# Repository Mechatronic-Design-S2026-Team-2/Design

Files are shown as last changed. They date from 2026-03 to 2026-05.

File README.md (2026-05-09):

# Hexapod Operation README

## Overview

This document describes basic setup, operation, charging, connection, and troubleshooting procedures for the hexapod robot.

---

## Aligning Motor Cranks

For the robot to maintain the expected alternating tripod gait, each input crank — the first bar extending from each motor — should point straight down.

This crank position corresponds to the highest point in the leg movement. If the cranks are not aligned this way, the control computer may incorrectly estimate leg position and phase. The robot may still operate, but gait smoothness may be reduced.

---

## Emergency Disable Switch

The switch mounted on the top surface of the robot disables motor control and the power relays.

| Switch Position | Function |
|---|---|
| `O` | Normal operation |
| `I` | Reset / disabled state |

To reset the motor control system, move the switch to `I` for a few moments, then return it to `O`.

---

## Charging the Robot Battery

1. Turn on the emergency disable switch by moving it to the `I` position.
2. Disconnect the XT90 connector from the board.
3. The battery may either be removed or charged in place.
4. Connect the charger to the smaller XT60 connector on the battery.
5. After the XT60 connector is attached, plug the charger power cord into a standard AC outlet.
6. Both charger LEDs should turn red.
7. When charging is complete, one charger LED will turn green.
8. Disconnect the charger from AC power first.
9. Disconnect the XT60 connector between the charger and the battery.

---

## Connecting to the Robot

### Wi-Fi

The robot hosts a Wi-Fi network with the following credentials:

| Field | Value |
|---|---|
| SSID | `team2` |
| Password | `MECHATRONICS` |
| Robot IP | `192.168.50.1` |

### Ethernet

When connected through the Jetson Ethernet port, the robot IP is:

```text
192.168.55.2
```

---

## SSH Access

The robot operating system credentials are:

| Field | Value |
|---|---|
| Username | `team2` |
| Password | `MECHATRONICS` |

Example SSH command over Wi-Fi:

```bash
ssh team2@192.168.50.1
```

Example SSH command over Ethernet:

```bash
ssh team2@192.168.55.2
```

---

## Accessing the Robot Control Interface

The robot control interface is available in a web browser.

### Over Wi-Fi

```text
http://192.168.50.1:8080
```

### Over Ethernet

```text
http://192.168.55.2:8080
```

Any modern desktop or laptop web browser should work.

When the control interface tab is active, pressing the displayed keyboard keys will command robot movement. The main map display can be used to view robot movement, the current occupancy grid map, generated maps, and waypoint placement.

Map saving and loading controls are located near the bottom of the right sidebar, along with key bindings, status information, and maximum velocity settings.

---

## Troubleshooting Wi-Fi

Under normal conditions, if the battery is charged, the Wi-Fi network should appear a few seconds after the battery is connected.

If the Wi-Fi network does not appear:

1. Check normal client-device Wi-Fi issues first.
2. Inspect the Jetson Nano located at the back-left corner inside the chassis.
3. Confirm that the green LED on the left side of the Jetson is on.
4. If the Jetson is not powered, check that the power jack connection is secure.

---

## Troubleshooting the Control Interface

If the robot and control device are connected, but the web control interface does not load:

1. Verify that the URL matches the connection method:
   - Wi-Fi: `http://192.168.50.1:8080`
   - Ethernet: `http://192.168.55.2:8080`
2. Open an SSH session to the robot.
3. Run the following commands:

```bash
docker exec -it jazzy bash
sudo systemctl restart orbslam2-realsense.service
sudo systemctl restart hexapod-ros2-full-launch.service
```

---

## Troubleshooting Robot Motion

If the robot does not move its legs when a nonzero motion command is sent, the most likely issue is the emergency disable state.

1. Move the emergency disable switch to `I`.
2. Wait a few moments.
3. Move the switch back to `O`.

The red PCB module on the right side of the robot has three LEDs. The two smaller LEDs should flash initially, then remain on.

If the LEDs do not remain on:

1. Disconnect and reconnect the USB-C cable connected to the ESP32.
2. Check the USB-A side of the cable connected to the Jetson.
3. Repeat the emergency switch reset procedure.

If the robot still does not move, restart the micro-ROS and ROS containers:

```bash
docker restart microros_agent
docker restart jazzy
```

---

## Foot Adjustment

The feet are height-adjustable relative to the leg assemblies. Before operation, verify that the feet make proper contact with the ground.

The legs may be moved manually when the robot is unpowered, or the robot may be walked using the standard control interface.

Adjustment guidance:

| Condition | Adjustment |
|---|---|
| Feet slip while walking | Rotate the threaded bolt holding the rubber foot pad counterclockwise |
| Feet extend too far and support wheels lose ground contact | Rotate the threaded bolt clockwise |

---

## Caster Wheel Adjustment

The caster wheels at each corner of the robot are also mounted using threaded bolts.

If the caster wheels have inconsistent heights, rotate the threaded bolts to adjust their height until the chassis is properly supported.

---

## Battery BMS Access

The battery includes a Bluetooth-enabled Daly BMS. BMS settings related to current output and protection can be accessed while the battery is actively charging or discharging.

| Field | Value |
|---|---|
| Bluetooth ID | `52V 25ah` |
| App | Daly BMS app |
| Password | `123456` |

To access the BMS:

1. Download the Daly BMS app.
2. Ensure the battery is actively charging or discharging.
3. Search for the Bluetooth ID `52V 25ah`.
4. Connect using password `123456`.

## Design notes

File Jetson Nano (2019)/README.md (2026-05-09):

# Hexapod ROS 2 Workspace

This workspace contains the Jetson-side ROS 2 Jazzy stack for the Klann-linkage hexapod. It is intended to live at `/ros2_ws` inside the existing ROS 2 container. The archive intentionally excludes `build/`, `install/`, and `log/` so it can be copied onto the Jetson and rebuilt in place.

The current stack assumes the RealSense D415 and ORB-SLAM2 process run on the bare-metal Jetson, while ROS 2, Nav2, SLAM Toolbox, the browser operator interface, hardware aggregation, and tripod gait controller run inside the `jazzy` container. The ESP32/micro-ROS bridge is expected to be provided separately by the `microros_agent` container.

## Current system architecture

### Bare-metal Jetson

`orbslam2-realsense.service` owns the RealSense D415 and runs the CUDA ORB-SLAM2 RGB-D frontend. It exports pose, map points, and a virtual planar scan to UDP port `5005`.

The Jetson also runs host-side systemd helpers:

- `hexapod-ros2-full-launch.service`: executes the full ROS 2 launch inside the already-running `jazzy` container.
- `hexapod-host-control.service`: exposes limited localhost-only HTTP actions for the browser GUI, such as restarting ORB-SLAM2 or the `microros_agent` container.

### ROS 2 container

The main runtime chain is:

```text
ORB-SLAM2 bare-metal UDP packets
  -> hexapod_orbslam_udp_bridge
  -> /hexapod/orbslam_odom
  -> /orbslam/map_points
  -> /scan_raw

/scan_raw
  -> scan_gate_node
  -> /scan      for SLAM Toolbox mapping
  -> /scan_nav  for Nav2 local obstacle checking

ESP32/micro-ROS motor odometry
  -> /motor_output_odom
  -> motor_state_aggregator_node
  -> /hexapod/motor_state

/hexapod/motor_state + linkage LUT
  -> body_state_estimator_node
  -> /hexapod/kinematic_odom

/hexapod/orbslam_odom + /hexapod/kinematic_odom + IMU
  -> weighted_odom_fusion_node
  -> /odom and odom -> base_link

/scan + odom -> base_link
  -> slam_toolbox
  -> /map and map -> odom

Browser teleop or Nav2 /cmd_vel_nav
  -> operator_interface_node
  -> /hexapod/cmd_vel_selected
  -> hexapod_tripod_gait
  -> /hexapod/phase_cmd
  -> phase_command_router_node
  -> /motor_rpm_cmd
  -> ESP32 / RS485 drives
```

The TF ownership is:

```text
slam_toolbox:                 map -> odom
weighted_odom_fusion_node:    odom -> base_link
static_transform_publisher:   base_link -> orbslam_scan_frame
```

Do not let ORB-SLAM and SLAM Toolbox both publish `map -> odom`. The current stack uses ORB-SLAM for visual odometry and virtual scan generation, then uses SLAM Toolbox to own the 2D map correction transform.

## Operator interface

The browser GUI is served by `hexapod_operator_interface`.

Default URL:

```text
http://192.168.50.1:8080/
```

Main functions:

- Estop, teleop, and waypoint mode selection.
- Browser teleop with `q/w/e/a/s/d/z/x/c`-style directional commands.
- Latched teleop command behavior, with stop via `s`, space, or the stop/estop control.
- Click-to-waypoint map interaction through Nav2.
- Occupancy grid display with pan and wheel zoom.
- To-scale birdseye hexapod skeleton overlay.
- Battery-voltage display from motor-state / motor-odom topics.
- Map save/load under `/ros2_ws/maps`.
- Mapping-enable toggle through `/hexapod/operator/map_updates_enabled`.
- Host-control buttons for limited restart actions.

Default GUI speeds:

```text
teleop linear speed:       0.50 m/s
teleop angular speed:      0.50 rad/s
teleop max linear speed:   3.00 m/s
teleop max angular speed:  3.00 rad/s
waypoint max linear speed: 0.50 m/s
waypoint max angular speed:0.50 rad/s
```

The operator arbiter publishes only one selected velocity stream to `/hexapod/cmd_vel_selected`. Nav2, teleop, and estop should not publish directly to the gait controller.

## Mapping and Nav2 behavior

The ORB-SLAM UDP bridge publishes virtual scan data on `/scan_raw`. The scan gate splits that into two streams:

```text
/scan_raw -> /scan      gated, restamped, used by SLAM Toolbox
/scan_raw -> /scan_nav  always live, restamped, used by Nav2 local costmap
```

Current mapping defaults:

```text
ORB-SLAM UDP port:                 5005
ORB-SLAM position scale:           1.214
ORB-SLAM scan range scale:         1.214
ORB-SLAM scan publish decimation:  3
scan gate mapping output rate:     about 3 Hz
scan gate nav output rate:         about 10 Hz
scan gate restamp outgoing scans:  true
SLAM Toolbox scan topic:           /scan
Nav2 local obstacle scan topic:    /scan_nav
```

The scan restamp behavior is intentional. The virtual scan is produced outside the container by ORB-SLAM and may carry timestamps that do not line up cleanly with the current TF cache. Restamping at the scan gate has been the more reliable path for SLAM Toolbox occupancy-grid generation on this Jetson setup.

Nav2 is configured for conservative but usable waypoint motion:

```text
Regulated Pure Pursuit desired linear velocity: 0.50 m/s
Regulated Pure Pursuit max angular velocity:   0.50 rad/s
velocity smoother max velocity:                [0.50, 0.0, 0.50]
velocity smoother max acceleration:            [1.00, 0.0, 1.20]
progress checker movement radius:              0.01 m
progress checker movement allowance:           60 s
```

The local costmap uses live `/scan_nav`; the global costmap primarily uses the static SLAM map plus inflation to reduce scan raytracing load.

## LCD1602 status display

The LCD node is in `hexapod_hardware_cpp` and is launched by default from the hardware stack. The current default is intentionally static URL-only output to avoid later character corruption from repeated LCD page updates.

Defaults:

```text
I2C device:     /dev/i2c-1
I2C address:    39 decimal / 0x27 hex
Displayed text: http://192.168.50.1:8080/
```

The node is non-fatal. If the I2C device or LCD backpack is unavailable, the rest of the launch should continue.

## Package overview

### `hexapod_hardware_cpp`

Hardware aggregation and state-estimation package.

Important nodes:

- `wt901_imu_node`: reads the WT901 IMU on `/dev/ttyTHS1` at 9600 baud and publishes raw IMU/euler topics.
- `motor_state_aggregator_node`: consumes compact ESP/micro-ROS motor odometry and publishes canonical `/hexapod/motor_state`.
- `body_state_estimator_node`: estimates body motion from motor phases and precomputed Klann linkage geometry.
- `weighted_odom_fusion_node`: publishes `/odom` and `odom -> base_link` using fused ORB-SLAM / kinematic / IMU information.
- `phase_command_router_node`: converts model-space `/hexapod/phase_cmd` into physical `/motor_rpm_cmd` messages for the ESP32 bridge.
- `lcd1602_status_node`: displays the operator URL on the I2C LCD1602 module.
- `klann_visualizer_node`: publishes marker geometry for the hexapod skeleton visualization.

Key topics:

```text
/motor_output_odom       input from ESP32/micro-ROS
/hexapod/motor_state     canonical motor state
/hexapod/kinematic_odom  kinematic odometry estimate
/hexapod/fused_odom      fused odometry
/odom                    Nav2/SLAM odometry topic
/hexapod/phase_cmd       model-space gait command
/motor_rpm_cmd           physical motor RPM command
/imu/data_raw
/imu/euler
```

### `hexapod_orbslam_udp_bridge`

ROS 2 bridge for the bare-metal ORB-SLAM2 frontend.

Functions:

- Listens on UDP port `5005`.
- Publishes `/hexapod/orbslam_odom`.
- Publishes sparse map points on `/orbslam/map_points`.
- Publishes virtual scan data on `/scan_raw`.
- Provides `orbslam_slam_toolbox.launch.py` for bridge + static scan TF + SLAM Toolbox.

Default frame and scale values preserve the known-good setup:

```text
map frame:             map
scan frame:            orbslam_scan_frame
scan x offset:         0.2794 m
position scale:        1.214
scan range scale:      1.214
axis conversion:       false by default for current ORB-SLAM output
packet stamp usage:    false by default
```

### `hexapod_operator_interface`

Browser operator UI, command arbiter, map utilities, and scan gate.

Important executables:

- `operator_interface_node`: HTTP GUI, operator mode state machine, teleop/waypoint command selection, battery display, map save/load endpoints.
- `scan_gate_node`: splits `/scan_raw` into `/scan` for mapping and `/scan_nav` for Nav2.

Key topics:

```text
/hexapod/cmd_vel_selected
/hexapod/operator/battery_voltage
/hexapod/operator/status_json
/hexapod/operator/map_updates_enabled
/hexapod/operator/scan_gate_status
/hexapod/operator/loaded_map
/scan_raw
/scan
/scan_nav
```

### `hexapod_tripod_gait`

C++ tripod gait command generator.

Current integrated-stack behavior:

- Subscribes to `/hexapod/cmd_vel_selected`.
- Uses `/hexapod/motor_state` for phase feedback.
- Publishes `/hexapod/phase_cmd`.
- Can latch the last command when configured.
- Outputs model-space phase commands rather than directly publishing RPM in the integrated hardware stack.

Leg order used internally:

```text
[RB, RM, RF, LF, LM, LB]
```

The hardware motor-state order is canonicalized by `hexapod_hardware_cpp`, with mappings preserved in the launch/config files.

### `hexapod_nav2_bringup`

Integrated bringup package for the full container-side stack.

Functions:

- Starts ORB-SLAM UDP bridge and SLAM Toolbox.
- Starts the hardware stack.
- Starts the scan gate.
- Starts the browser operator interface.
- Starts the tripod gait controller in integrated phase-command mode.
- Starts Nav2 controller/planner/behavior/BT/smoother/waypoint lifecycle nodes.
- Provides tuned Nav2 parameters for the hexapod path.

The full-stack launch is:

```bash
ros2 launch hexapod_nav2_bringup hexapod_nav2.launch.py
```

### `hexapod_control_interfaces`

Custom message definitions used between hardware, gait, state-estimation, and visualization nodes.

Primary messages:

```text
HexapodMotorState.msg
LegPhaseCommand.msg
KlannBodyState.msg
LegActuationState.msg
```

### `dsy_motor_msgs`

Motor command and odometry messages used by the ESP32/micro-ROS side.

This package contains the compact motor odometry and RPM command interfaces used by the ROS-side hardware aggregation package.

### `hexapod_nav_cpp`

Earlier C++ Nav2/controller-plugin work. It remains in the workspace for reference and future controller-plugin development, but the current operator/hardware path primarily uses `hexapod_tripod_gait` plus `hexapod_nav2_bringup`.

## Build inside the existing ROS 2 container

Full workspace build:

```bash
cd /ros2_ws
source /opt/ros/jazzy/setup.bash
colcon build --symlink-install
source install/setup.bash
```

Common incremental build after edits:

```bash
cd /ros2_ws
source /opt/ros/jazzy/setup.bash
colcon build --symlink-install --packages-select \
  hexapod_hardware_cpp \
  hexapod_orbslam_udp_bridge \
  hexapod_operator_interface \
  hexapod_tripod_gait \
  hexapod_nav2_bringup
source install/setup.bash
```

If custom message definitions changed, build through dependent packages instead of rebuilding only one downstream package.

## Manual full launch

```bash
ros2 launch hexapod_nav2_bringup hexapod_nav2.launch.py \
  start_orbslam_slamtoolbox:=true \
  start_hardware_stack:=true \
  start_tripod_controller:=true \
  start_operator_interface:=true \
  operator_http_port:=8080 \
  operator_default_mode:=estop \
  operator_latch_teleop_commands:=true \
  operator_keyboard_linear_mps:=0.50 \
  operator_keyboard_angular_radps:=0.50 \
  operator_max_linear_mps:=3.00 \
  operator_max_angular_radps:=3.00 \
  operator_waypoint_max_linear_mps:=0.50 \
  operator_waypoint_max_angular_radps:=0.50 \
  orbslam_scan_publish_decimation:=3 \
  scan_gate_restamp_scans:=true \
  orbslam_stamp_scan_with_latest_pose:=false
```

The browser UI should come up in estop mode. Movement should require an operator mode change from the GUI.

## Host autostart

The ROS 2 container is assumed to already start automatically. The provided host-side service only runs the full ROS launch inside that existing container.

Install or update autostart on the Jetson host:

```bash
cd /ros2_ws
sudo ./scripts/install_hexapod_autostart.sh
sudo systemctl daemon-reload
sudo systemctl restart hexapod-ros2-full-launch.service
sudo journalctl -u hexapod-ros2-full-launch.service -f
```

The service uses `docker exec` against the configured container name, normally `jazzy`.

Configuration defaults are installed under:

```text
/etc/default/hexapod-ros2-full-launch
```

## Host-control helper

The host-control helper is optional but needed for GUI restart buttons.

Install it on the Jetson host:

```bash
cd /ros2_ws
sudo ./scripts/install_hexapod_host_control.sh
curl http://127.0.0.1:18080/status
```

The helper is intentionally narrow. It is intended to restart only known host services/containers such as:

```text
orbslam2-realsense.service
microros_agent Docker container
```

## Common verification commands

Topic rates:

```bash
ros2 topic hz /scan_raw
ros2 topic hz /scan
ros2 topic hz /scan_nav
ros2 topic hz /map
ros2 topic hz /odom
ros2 topic hz /hexapod/motor_state
```

Command path:

```bash
ros2 topic echo /hexapod/cmd_vel_selected
ros2 topic echo /hexapod/phase_cmd
ros2 topic echo /motor_rpm_cmd
```

Mapping and scan gate:

```bash
ros2 topic echo /hexapod/operator/scan_gate_status
ros2 topic echo /hexapod/operator/map_updates_enabled
ros2 run tf2_ros tf2_echo map base_link
```

Operator GUI:

```bash
curl http://192.168.50.1:8080/api/state
```

LCD:

```bash
ls /dev/i2c-*
i2cdetect -y -r 1
```

## Expected key topics

```text
/map
/map_updates
/scan_raw
/scan
/scan_nav
/odom
/tf
/tf_static
/hexapod/orbslam_odom
/hexapod/motor_state
/hexapod/kinematic_odom
/hexapod/fused_odom
/hexapod/cmd_vel_selected
/hexapod/phase_cmd
/motor_rpm_cmd
/motor_output_odom
/imu/data_raw
/imu/euler
/hexapod/operator/status_json
/hexapod/operator/battery_voltage
/hexapod/operator/scan_gate_status
```

## Runtime troubleshooting

If `/scan_raw`, `/scan`, and `/scan_nav` publish but `/map` does not publish, check SLAM Toolbox scan acceptance and TF:

```bash
ros2 topic hz /scan
ros2 run tf2_ros tf2_echo odom base_link
ros2 topic echo /hexapod/operator/scan_gate_status
```

If GUI teleop changes mode but no motor command appears, check the command chain:

```bash
ros2 param get /hexapod_tripod_gait cmd_vel_topic
ros2 topic echo /hexapod/cmd_vel_selected
ros2 topic echo /hexapod/phase_cmd
ros2 topic echo /motor_rpm_cmd
```

Expected gait parameter:

```text
/hexapod/cmd_vel_selected
```

If `/motor_output_odom` is live but `/hexapod/motor_state` is not, check the hardware aggregator and message compatibility. If `/hexapod/motor_state` is live but phase feedback is rejected, verify the gait node's motor-state strictness parameters and array completeness.

If Nav2 waypoint commands are too slow, compare the stages:

```bash
ros2 topic echo /cmd_vel_nav_raw
ros2 topic echo /cmd_vel_nav
ros2 topic echo /hexapod/cmd_vel_selected
ros2 topic echo /hexapod/phase_cmd
```

This identifies whether the limit is coming from Nav2, the velocity smoother, the operator arbiter, or the tripod gait conversion.

If Fast DDS shared-memory lock errors appear in Docker, the autostart script sets:

```text
FASTDDS_BUILTIN_TRANSPORTS=UDPv4
```

This avoids the repeated `fastrtps_port... open_and_lock_file failed` errors in the host-networked container setup.

## Offline Jetson note

Do not rebuild the Docker image on the offline Jetson unless the required apt packages are already cached or the image was built on another machine and transferred over. This workspace contains source and host deployment scripts only. It does not contain compiled ROS build products.

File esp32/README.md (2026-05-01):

# DSY-RS ROS 2 velocity control bundle - micro-ROS over UART0 custom transport

This bundle targets the current working single-owner RS485 version and changes only the micro-ROS transport layer:

- `host_ws/src/dsy_motor_msgs`: custom ROS 2 messages.
- `host_ws/src/dsy_motor_gui`: simple ROS 2 Tkinter slider GUI.
- `esp32_main`: ESP-IDF `main/` replacement files using micro-ROS over UART0 custom transport.
- `microros_extra_packages/dsy_motor_msgs`: copy of the custom interface package for `micro_ros_espidf_component/extra_packages`.
- `serial_transport_colcon_meta_snippet.json`: the key transport change you must merge into the component `colcon.meta`.

## Resulting port usage

- RS485 motor bus stays on UART2: TX=17, RX=16, DE/RE=4.
- micro-ROS uses UART0 through the ESP32 board USB-UART bridge: TX0/RX0.
- GPIO18 remains the servo-enable output for the external optocoupled interface.

## Host ROS 2 workspace

```bash
mkdir -p ~/dsy_ros_ws/src
cp -r host_ws/src/dsy_motor_msgs ~/dsy_ros_ws/src/
cp -r host_ws/src/dsy_motor_gui ~/dsy_ros_ws/src/
cd ~/dsy_ros_ws
source /opt/ros/jazzy/setup.bash
rosdep install --from-paths src --ignore-src -y
colcon build
source install/setup.bash
```

Run the GUI:

```bash
ros2 launch dsy_motor_gui dsy_motor_slider_gui.launch.py
```

## ESP-IDF project setup

Assume your ESP-IDF project root is `/path/to/servo_bridge`.

### 1. Clone the micro-ROS ESP-IDF component

```bash
cd /path/to/servo_bridge
mkdir -p components
cd components
git clone https://github.com/micro-ROS/micro_ros_espidf_component.git
```

### 2. Install build dependencies in the IDF Python environment

Use an IDF shell, not a shell with ROS sourced.

```bash
. $IDF_PATH/export.sh
pip3 install catkin_pkg lark-parser colcon-common-extensions
```

### 3. Copy the UART transport bridge files into your project

```bash
cd /path/to/servo_bridge
mkdir -p main
cp -r /path/to/this_bundle/esp32_main/* main/
```

### 4. Add the custom interface package to the micro-ROS component

```bash
cp -r /path/to/this_bundle/microros_extra_packages/dsy_motor_msgs \
  /path/to/servo_bridge/components/micro_ros_espidf_component/extra_packages/
```

### 5. Enable custom transport in the component `colcon.meta`

Edit:

```text
/path/to/servo_bridge/components/micro_ros_espidf_component/colcon.meta
```

and add:

```json
"-DRMW_UXRCE_TRANSPORT=custom"
```

to the `rmw_microxrcedds` `cmake-args` list.

A snippet is included in `serial_transport_colcon_meta_snippet.json`.

### 6. Clean and rebuild micro-ROS libraries

```bash
cd /path/to/servo_bridge
idf.py clean-microros
idf.py set-target esp32
idf.py menuconfig
idf.py build
idf.py flash
```

## ESP `menuconfig`

Set the project values under the custom `DSY RS485 Bench-Safe Control` menu:

- `SERVO_RS485_UART_TXD = 17`
- `SERVO_RS485_UART_RXD = 16`
- `SERVO_RS485_UART_DE_RE = 4`
- `SERVO_RS485_BAUD_RATE = 38400`
- `MICRO_ROS_UART_BAUD_RATE = 460800`
- `SERVO_SAFE_MAX_MOTOR_RPM = 120`
- `SERVO_SAFE_TORQUE_LIMIT_TENTHS_PERCENT_RATED = 200`
- `SERVO_TEST_ACTIVE_DRIVE_COUNT = 1` for first bring-up, then raise as needed.

Do not run `idf.py monitor` at the same time as the micro-ROS serial agent, because both use the same USB-UART path on UART0.

## micro-ROS Agent on the ROS 2 Jazzy laptop

### Preferred: source build on the laptop

```bash
mkdir -p ~/uros_agent_ws/src
cd ~/uros_agent_ws/src
git clone https://github.com/micro-ROS/micro-ROS-Agent.git
cd ~/uros_agent_ws
source /opt/ros/jazzy/setup.bash
rosdep update
rosdep install --from-paths src --ignore-src -y
colcon build --symlink-install
source install/setup.bash
```

Run the agent:

```bash
ros2 run micro_ros_agent micro_ros_agent serial --dev /dev/ttyUSB0 -b 460800 -v6
```

Replace `/dev/ttyUSB0` with your actual adapter node.

### Docker fallback

```bash
docker run -it --rm -v /dev:/dev --privileged --net=host \
  microros/micro-ros-agent:kilted serial --dev /dev/ttyUSB0 -b 460800 -v6
```

## Suggested bring-up order

1. Flash the ESP32.
2. Disconnect `idf.py monitor` if it is open.
3. Start the serial micro-ROS agent on the laptop.
4. Power the drive and ESP32.
5. Source `~/dsy_ros_ws/install/setup.bash`.
6. Run `ros2 topic list` and confirm the `/dsy_motor_N/*` topics appear.
7. Start the GUI and command very small velocities first.

## Safety defaults preserved

- Speed mode is still used for direct velocity control.
- Torque is capped at `200` DSY units (`20.0% rated`) to stay conservative on a 30 V / 3 A bench supply without external brake resistors.
- Maximum motor speed stays at `120 rpm`.
- Useful odometry is the 1:50 gearbox output shaft; the bridge converts motor-side feedback before publishing.

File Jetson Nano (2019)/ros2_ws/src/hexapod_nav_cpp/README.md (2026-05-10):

# hexapod_nav_cpp — hardware-safe MPPI phase controller

This package is a drop-in controller folder for the current hexapod ROS 2 workspace.  It publishes `hexapod_control_interfaces/msg/LegPhaseCommand` on `/hexapod/phase_cmd`; the existing `phase_command_router_node` remains responsible for converting model-frame leg phase commands to physical `/motor_rpm_cmd` in ESP wire order.

## Current control path

```text
/plan
  -> klann_mppi_controller_node
  -> /hexapod/phase_cmd
  -> phase_command_router_node
  -> /motor_rpm_cmd
  -> ESP32 sweep bridge
```

Feedback path:

```text
/motor_output_odom
  -> motor_state_aggregator_node
  -> /hexapod/motor_state
  -> body_state_estimator_node
  -> /hexapod/body_state
  -> klann_mppi_controller_node
```

The standalone MPPI node does not require ORB-SLAM, `/odom`, `/map`, or `slam_toolbox`.  It consumes `/hexapod/body_state` and `/plan`.

## Hardware-safe changes

Compared with the earlier MPPI package, this version uses conservative defaults that matched the stable bringup behavior:

- `nominal_phase_rate_rad_s = 0.25`
- `phase_rate_limit_rad_s = 0.45`
- `linear_speed_limit_mps = 0.03`
- `angular_speed_limit_rps = 0.08`
- low MPPI perturbation noise
- high phase-sync and control-smoothness penalties
- `forward_phase_rate_sign = -1.0`
- `mirror_kinematics_across_y_axis = true`

It also adds `lock_forward_phase_rate_sign`.  During near-straight forward walking, MPPI samples are not allowed to reverse individual leg phase-rate signs.  This prevents the observed leg direction thrashing and reduces risk of single-turn encoder unwrap errors.

## Build

Only this package needs rebuilding when replacing this folder:

```bash
cd /ros2_ws
source /opt/ros/jazzy/setup.bash
colcon build --symlink-install --packages-select hexapod_nav_cpp
source install/setup.bash
```

No rebuild is required for `dsy_motor_msgs`, `hexapod_hardware_cpp`, `hexapod_orbslam_udp_bridge`, or the ESP firmware unless those packages were changed separately.

## Launch

Start the hardware stack first and wait for the startup pose to complete:

```bash
ros2 launch hexapod_hardware_cpp hardware_stack.launch.py
```

Then run the controller:

```bash
ros2 launch hexapod_nav_cpp controller_stack.launch.py
```

Publish a short local test path in `hexapod_kinematic_odom` coordinates:

```bash
ros2 topic pub --once /plan nav_msgs/msg/Path "{
  header: {frame_id: 'hexapod_kinematic_odom'},
  poses: [
    {header: {frame_id: 'hexapod_kinematic_odom'}, pose: {position: {x: 0.0, y: 0.0, z: 0.0}, orientation: {w: 1.0}}},
    {header: {frame_id: 'hexapod_kinematic_odom'}, pose: {position: {x: 0.45, y: 0.0, z: 0.0}, orientation: {w: 1.0}}}
  ]
}"
```

Stop by publishing an empty plan:

```bash
ros2 topic pub --once /plan nav_msgs/msg/Path "{header: {frame_id: 'hexapod_kinematic_odom'}, poses: []}"
```

## Main tuning knobs

`lock_forward_phase_rate_sign: true` should remain enabled for real hardware until the encoder/RS485 path is proven robust under higher rates.

Increase speed in this order:

1. `nominal_phase_rate_rad_s`
2. `phase_rate_limit_rad_s`
3. `linear_speed_limit_mps`

Do not increase MPPI noise first.  Increasing `phase_rate_noise_std` before the gait is stable reintroduces leg reversals.

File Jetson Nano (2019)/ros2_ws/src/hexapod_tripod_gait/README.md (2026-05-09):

# hexapod_tripod_gait

Simple ROS 2 C++ bridge from standard teleop velocity topics to the six-motor DSY micro-ROS RPM interface.

Leg order is fixed to:

```text
[0] right_back
[1] right_middle
[2] right_front
[3] left_front
[4] left_middle
[5] left_back
```

Forward RPM convention:

```text
right legs: positive RPM for forward
left legs:  negative RPM for forward
forward_motor_signs = [+, +, +, -, -, -]
```

The node publishes `dsy_motor_msgs/msg/MotorRpmArray` on `motor_rpm_cmd` and subscribes to `dsy_motor_msgs/msg/MotorOutputOdometryArray` on `motor_output_odom` using best-effort QoS. It accepts both `geometry_msgs/msg/Twist` on `cmd_vel` and `geometry_msgs/msg/TwistStamped` on `cmd_vel_stamped`; set either topic parameter to an empty string to disable it.

By default, `latch_last_teleop_command: true` keeps the last received teleop command active indefinitely. The teleop app does not need to publish a continuous stream. Send an explicit zero `Twist` to stop the robot. By default, `publish_unchanged_commands: false` suppresses repeated publication of the same quantized six-motor RPM vector.

Tripod grouping:

```text
tripod A = [right_middle, left_front, left_back] = indices [1, 3, 5]
tripod B = [right_back, right_front, left_middle] = indices [0, 2, 4]
```

The phase-lock term uses `output_phase_rad` to keep tripod B approximately pi radians offset from tripod A while translating. Pure yaw defaults to no phase-lock correction because opposite-side turning can make a single common phase reference fight the turn command.

## Feedback inputs

The node can subscribe to:

```text
imu_topic          sensor_msgs/msg/Imu              default: imu/data_raw
euler_topic        geometry_msgs/msg/Vector3Stamped default: imu/euler
euler_vector_topic geometry_msgs/msg/Vector3        default: disabled
```

`imu_feedback_enabled` is the master switch for the raw IMU subscription. If it is false, yaw-rate feedback, acceleration-derived velocity feedback, and raw-IMU quaternion tilt feedback are unavailable.

`euler_feedback_enabled` is the switch for the explicit Euler topic subscription. Euler feedback uses `x=roll`, `y=pitch`, `z=yaw`; set `euler_angles_are_degrees: true` if the topic is in degrees.

Raw IMU yaw feedback uses `angular_velocity.z`. Keep `yaw_rate_feedback_kp` at zero until the yaw-rate sign is verified.

Raw IMU acceleration feedback uses one selected linear acceleration axis, integrates it into a leaky forward-velocity estimate, then compares that estimate against `cmd_vel.linear.x`:

```text
velocity_error = commanded_linear_x - estimated_linear_velocity
linear_correction = linear_velocity_feedback_kp * velocity_error
adjusted_linear_x = commanded_linear_x + clamp(linear_correction)
```

It is disabled by default because accelerometer-only velocity estimates drift. Before enabling it, verify `linear_accel_axis`, `linear_accel_sign`, and the IMU mounting. Start with a low gain.

## Raw-encoder ESP firmware / hardware-stack feedback

For the current ESP firmware, `motor_output_odom.output_phase_rad[]` is no longer a usable
output-shaft phase signal; it carries raw single-turn encoder counts. Run the
hardware stack's `motor_state_aggregator_node` and feed this controller from:

```text
/hexapod/motor_state
```

That topic is `hexapod_control_interfaces/msg/HexapodMotorState` in canonical order:

```text
[RF, RM, RB, LF, LM, LB]
```

This controller still keeps its internal command order:

```text
[RB, RM, RF, LF, LM, LB]
```

so it uses the default mapping:

```yaml
internal_to_motor_state_index: [2, 1, 0, 3, 4, 5]
```

With motor-state feedback, keep:

```yaml
use_motor_state_feedback: true
use_compact_odometry_feedback: false
phase_direction_signs: [1.0, 1.0, 1.0, 1.0, 1.0, 1.0]
phase_correction_motor_signs: [-1.0, -1.0, -1.0, 1.0, 1.0, 1.0]
```

The all-positive `phase_direction_signs` are intentional: the hardware aggregator already
applies the raw-count anchoring, side signs, and canonical leg ordering. The separate
`phase_correction_motor_signs` convert model phase correction back to physical motor RPM.

When `phase_command_router_node` is running, use phase-command output:

```bash
ros2 launch hexapod_tripod_gait tripod_gait.launch.py \
  command_output_mode:=phase \
  use_motor_state_feedback:=true \
  use_compact_odometry_feedback:=false
```

In this mode the teleop node publishes ROS-level `hexapod/phase_cmd` keepalives at up to
10 Hz so the router does not time out; the router still suppresses unchanged
`/motor_rpm_cmd` writes to avoid wasting ESP/RS485 bus bandwidth.

## Build

From a ROS 2 workspace:

```bash
mkdir -p ~/hexapod_tripod_ws/src
cp -r dsy_motor_msgs hexapod_tripod_gait ~/hexapod_tripod_ws/src/
cd ~/hexapod_tripod_ws
source /opt/ros/jazzy/setup.bash
colcon build --symlink-install --packages-select dsy_motor_msgs hexapod_tripod_gait
source install/setup.bash
```

If your workspace already has `dsy_motor_msgs` with the same message definitions, copy only `hexapod_tripod_gait` into `src` and build that package against your existing message package.

## Launch

Default launch:

```bash
ros2 launch hexapod_tripod_gait tripod_gait.launch.py
```

Turn off all raw IMU feedback and the explicit Euler topic feedback from launch:

```bash
ros2 launch hexapod_tripod_gait tripod_gait.launch.py \
  imu_feedback_enabled:=false \
  euler_feedback_enabled:=false
```

Tune phase-lock gain from launch:

```bash
ros2 launch hexapod_tripod_gait tripod_gait.launch.py \
  phase_kp_rpm_per_rad:=15.0 \
  max_phase_correction_rpm:=60.0
```

Enable yaw-rate feedback after confirming IMU yaw-rate sign:

```bash
ros2 launch hexapod_tripod_gait tripod_gait.launch.py \
  imu_feedback_enabled:=true \
  yaw_rate_feedback_enabled:=true \
  yaw_rate_feedback_kp:=0.10 \
  max_yaw_rate_correction_radps:=0.25
```

Enable acceleration-derived linear velocity feedback cautiously:

```bash
ros2 launch hexapod_tripod_gait tripod_gait.launch.py \
  imu_feedback_enabled:=true \
  linear_accel_feedback_enabled:=true \
  linear_velocity_feedback_kp:=0.10 \
  max_linear_velocity_correction_mps:=0.05 \
  linear_accel_axis:=0 \
  linear_accel_sign:=1.0 \
  accel_deadband_mps2:=0.15 \
  accel_velocity_leak_tau_sec:=1.0
```

## Test commands

Slow forward latched command. Because latching is enabled by default, one publish is enough. Expected RPM sign pattern is `[+, +, +, -, -, -]`:

```bash
ros2 topic pub --once /cmd_vel geometry_msgs/msg/Twist "{linear: {x: 0.10}, angular: {z: 0.0}}"
```

Explicit stop command:

```bash
ros2 topic pub --once /cmd_vel geometry_msgs/msg/Twist "{linear: {x: 0.0}, angular: {z: 0.0}}"
```

Slow in-place positive yaw command. With the default mapping, this makes the right side walk forward and the left side walk backward:

```bash
ros2 topic pub --rate 5 /cmd_vel geometry_msgs/msg/Twist "{linear: {x: 0.0}, angular: {z: 0.20}}"
```

Monitor the outgoing motor RPM array:

```bash
ros2 topic echo /motor_rpm_cmd
```

Monitor command propagation fields from the ESP bridge:

```bash
ros2 topic echo /motor_output_odom
```

## Main tuneable launch arguments

`linear_rpm_per_mps`, `yaw_rpm_per_radps`, `max_motor_rpm`, `phase_kp_rpm_per_rad`, `max_phase_correction_rpm`, `yaw_rate_feedback_kp`, `linear_velocity_feedback_kp`, `max_linear_velocity_correction_mps`, `tilt_safety_enabled`, `imu_feedback_enabled`, and `euler_feedback_enabled` are exposed directly as launch arguments.

All six-element arrays in the YAML use `[right_back, right_middle, right_front, left_front, left_middle, left_back]` order.

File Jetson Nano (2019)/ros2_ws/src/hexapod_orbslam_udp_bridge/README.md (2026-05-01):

# hexapod_orbslam_udp_bridge

ROS 2 Jazzy C++ UDP bridge for the bare-metal ORB-SLAM2 RealSense process.

It listens for ORB-SLAM UDP packets and publishes:

- `/odom` as `nav_msgs/msg/Odometry`
- optional TF `odom -> base_link`
- `/scan` as `sensor_msgs/msg/LaserScan` for `slam_toolbox`
- `/orbslam/map_points` as `sensor_msgs/msg/PointCloud2` for RViz/debug

The sparse ORB-SLAM map-point cloud is not the occupancy map. The occupancy map is produced by `slam_toolbox` from `/scan`.

## Patch notes for slam_toolbox

This version changes the bridge defaults for occupancy mapping:

- Enables virtual-scan support by default.
- Publishes scan in `orbslam_scan_frame`, with a static `base_link -> orbslam_scan_frame` transform.
- Converts the virtual scan from camera optical convention into ROS laser convention.
- Reverses the scan range order so left/right are correct in ROS.
- Stamps scans with the latest pose stamp to avoid `slam_toolbox` TF extrapolation failures.
- Defaults `base_frame` to `base_link`.
- Defaults camera offset for an 11 inch forward D415: `camopt_to_base_z = -0.2794`, `scan_x = 0.2794`.

## Frame convention

ORB-SLAM/OpenCV camera optical axes:

```text
+X = right
+Y = down
+Z = forward
```

ROS body/laser axes:

```text
+X = forward
+Y = left
+Z = up
```

For map/pose conversion, keep:

```yaml
convert_orbslam_to_ros_axes: true
```

For scan conversion, keep:

```yaml
convert_scan_optical_to_ros: true
```

## Camera offset

The bridge uses two offset conventions.

`camopt_to_base_{x,y,z}` is the vector from the camera optical origin to `base_link`, expressed in camera optical axes. For a camera 0.2794 m forward of `base_link`:

```text
camopt_to_base_x = 0.0
camopt_to_base_y = 0.0
camopt_to_base_z = -0.2794
```

The scan static transform is expressed in `base_link` axes. For the same 0.2794 m forward camera:

```text
scan_x = 0.2794
scan_y = 0.0
scan_z = 0.0
```

Set the real camera height using `scan_z` and the corresponding camera optical offset using `camopt_to_base_y = camera_height_above_base`.

## Build in the container

```bash
cd /ros2_ws
colcon build --symlink-install --packages-select hexapod_orbslam_udp_bridge
source install/setup.bash
```

## Install patched systemd service on bare metal

Copy the service from this package or from the zip's `systemd/` directory:

```bash
sudo cp /ros2_ws/src/hexapod_orbslam_udp_bridge/systemd/orbslam2-realsense.service /etc/systemd/system/orbslam2-realsense.service
sudo systemctl daemon-reload
sudo systemctl restart orbslam2-realsense.service
sudo journalctl -u orbslam2-realsense.service -f
```

Important service fixes:

- The sender uses `ORBSLAM_UDP_IP`, not `ORBSLAM_UDP_HOST`.
- `ORBSLAM_UDP_SCAN_ENABLE=1` must remain enabled.
- The ROS 2 container should use `--net=host` if the service sends to `127.0.0.1`.

## Run bridge only

```bash
ros2 launch hexapod_orbslam_udp_bridge udp_bridge.launch.py
```

For your known 11 inch forward camera offset, the defaults are already:

```bash
camopt_to_base_z:=-0.2794
scan_x:=0.2794
```

If the camera is also 0.25 m above `base_link`, launch with:

```bash
ros2 launch hexapod_orbslam_udp_bridge udp_bridge.launch.py \
  camopt_to_base_y:=0.25 \
  scan_z:=0.25
```

## Run bridge plus slam_toolbox

```bash
ros2 launch hexapod_orbslam_udp_bridge orbslam_slam_toolbox.launch.py
```

This uses:

```text
config/slam_toolbox_orbslam_scan.yaml
```

The expected TF tree is:

```text
map -> odom -> base_link -> orbslam_scan_frame
```

`slam_toolbox` publishes `map -> odom`; the bridge publishes `odom -> base_link`; the launch file publishes the static `base_link -> orbslam_scan_frame`.

## Debug

```bash
ros2 topic hz /scan
ros2 topic echo /scan --once
ros2 topic hz /odom
ros2 topic echo /odom --once
ros2 run tf2_tools view_frames
ros2 topic echo /map --once
```

If `/scan` is missing, check the bare-metal service environment first:

```bash
sudo systemctl show orbslam2-realsense.service -p Environment
sudo journalctl -u orbslam2-realsense.service -n 100
```

If UDP packets are not reaching the container and the service sends to `127.0.0.1`, recreate the ROS 2 container with host networking.

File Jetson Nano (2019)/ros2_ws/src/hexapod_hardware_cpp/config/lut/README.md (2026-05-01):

Precomputed 17-bit Klann lookup tables belong in this directory.

Generate them on a desktop or other fast machine before deployment on the Jetson:

```bash
ros2 run hexapod_hardware_cpp klann_lut_generator \
  /path/to/linkage_measured.yaml \
  /path/to/output_dir \
  131072
```

That writes one `.klut` file per leg plus `linkage_precomputed.yaml`.
Point `linkage_yaml` at that generated YAML for deployment.

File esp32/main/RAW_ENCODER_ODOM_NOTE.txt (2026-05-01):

This patch changes runtime odometry publishing to send raw P18.32/P18.33 single-turn encoder counts instead of ESP-computed output phase.

Compatibility note:
- The ROS message type is not changed in this ESP-IDF main directory.
- Existing MotorOutputOdometryArray.output_phase_rad[6] is reused to carry raw encoder counts as float values.
- For M17S 17-bit encoders, valid raw counts are 0..131071, which are exactly representable in float32.
- motor_velocity_bridge_status.absolute_position_counts[] mirrors the same raw count for local status/debug.
- The ESP no longer performs modulo unwrap, output gear-ratio division, or radians conversion in the runtime odometry path.

Controller-side interpretation:
  raw_motor_angle_mod_rad = 2*pi*raw_count/CONFIG_SERVO_ENCODER_COUNTS_PER_MOTOR_REV

For continuous output phase, unwrap the raw modulo motor count on the ROS-side model/controller first, then calculate:
  continuous_output_phase_rad = unwrapped_motor_counts*2*pi/(CONFIG_SERVO_ENCODER_COUNTS_PER_MOTOR_REV*CONFIG_SERVO_OUTPUT_GEAR_RATIO)

Use the timing fields, commanded RPM, contact state, and IMU/model constraints upstream to choose the correct wrap count.

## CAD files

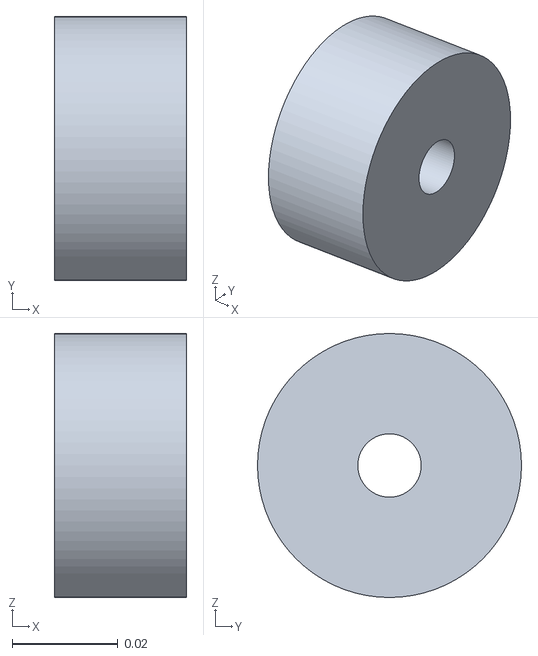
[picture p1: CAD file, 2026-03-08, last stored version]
hexa_ws/src/hexapod_mujoco_nav/mjcf/assets/round_joint.stl
0.025 x 0.05 x 0.05

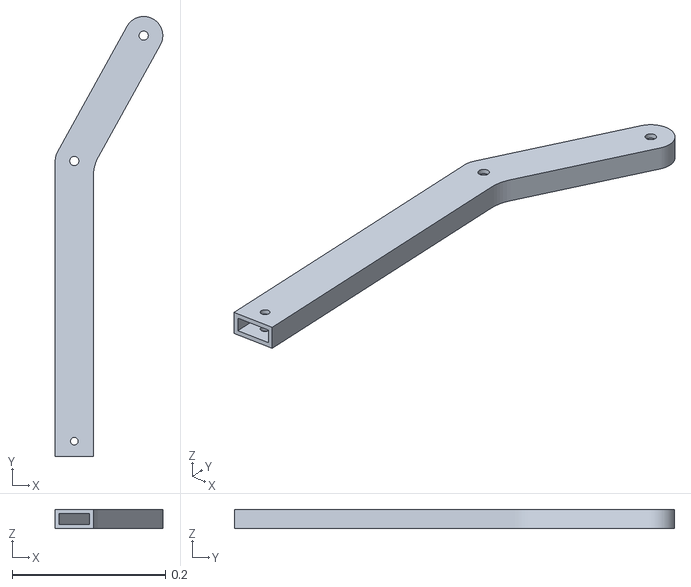
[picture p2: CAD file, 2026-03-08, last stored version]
hexa_ws/src/hexapod_mujoco_nav/mjcf/assets/left_triangle_link.stl
0.141 x 0.575 x 0.025

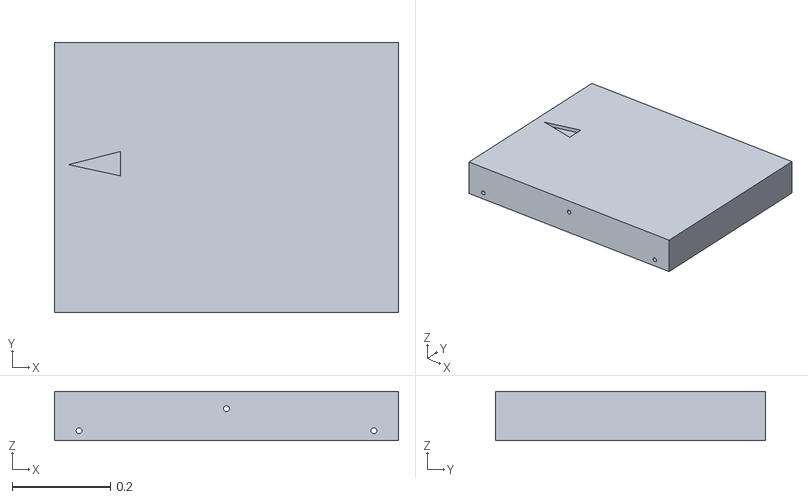
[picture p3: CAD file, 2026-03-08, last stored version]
hexa_ws/src/hexapod_mujoco_nav/mjcf/assets/base_link.stl
0.7 x 0.55 x 0.1

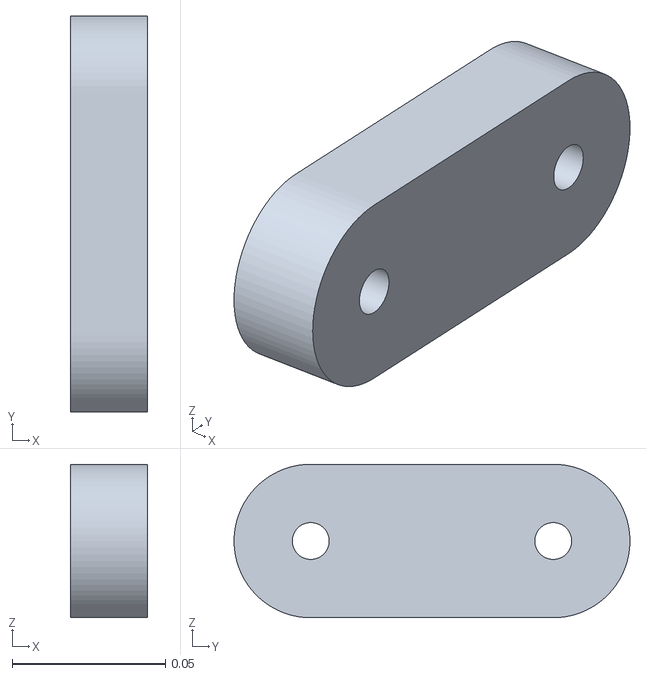
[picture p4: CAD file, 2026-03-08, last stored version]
hexa_ws/src/hexapod_mujoco_nav/mjcf/assets/left_down_link.stl
0.025 x 0.129 x 0.05

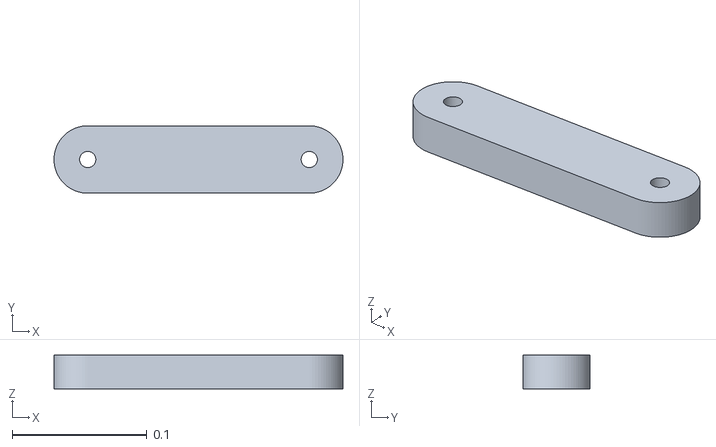
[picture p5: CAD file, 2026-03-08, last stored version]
hexa_ws/src/hexapod_mujoco_nav/mjcf/assets/top_link.stl
0.214 x 0.05 x 0.025

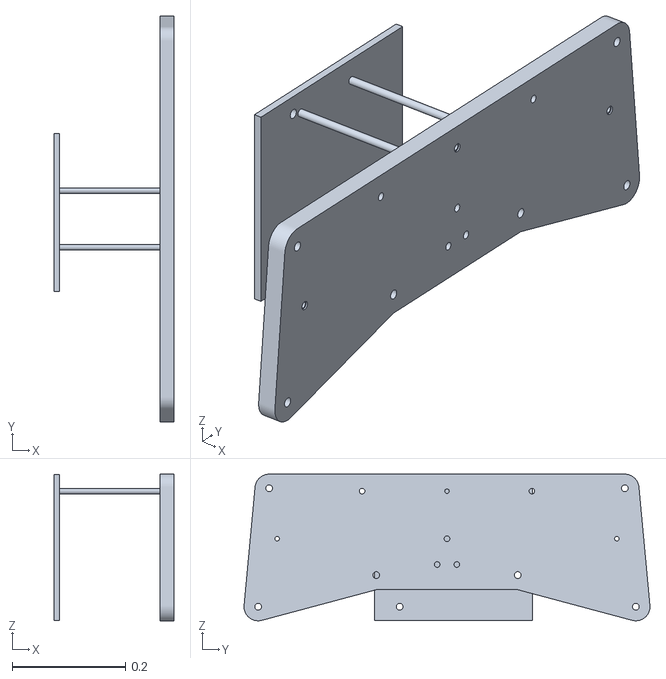
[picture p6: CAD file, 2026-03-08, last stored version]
hexa_ws/src/hexapod_mujoco_nav/mjcf/assets/rightmidbase.stl
0.212 x 0.717 x 0.259

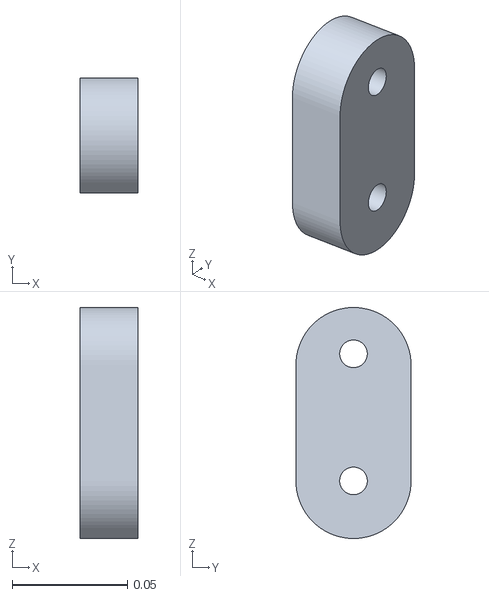
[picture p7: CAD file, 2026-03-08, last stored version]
hexa_ws/src/hexapod_mujoco_nav/mjcf/assets/right_down_link.stl
0.025 x 0.05 x 0.1

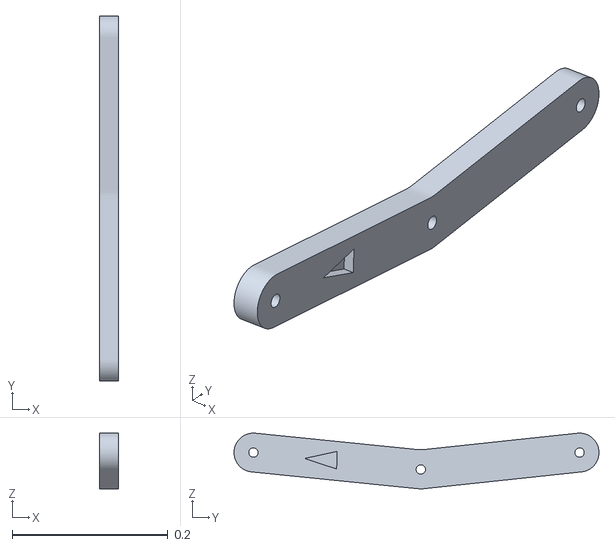
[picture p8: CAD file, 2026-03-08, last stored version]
hexa_ws/src/hexapod_mujoco_nav/mjcf/assets/middle_triangle_link.stl
0.025 x 0.469 x 0.0717

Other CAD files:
hexa_ws/src/hexapod_mujoco_nav/mjcf/assets/fusioncomponent.stl

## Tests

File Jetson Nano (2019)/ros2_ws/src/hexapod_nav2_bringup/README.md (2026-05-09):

# hexapod_nav2_bringup

Nav2 bringup for the integrated hexapod ROS 2 stack.

This package expects the uploaded host-side packages to be present:

- `dsy_motor_msgs`
- `hexapod_control_interfaces`
- `hexapod_hardware_cpp`
- `hexapod_orbslam_udp_bridge`
- `hexapod_tripod_gait`

Default launch chain:

```text
Nav2 controller_server -> velocity_smoother -> /cmd_vel
hexapod_tripod_gait -> hexapod/phase_cmd
hexapod_hardware_cpp/phase_command_router_node -> /motor_rpm_cmd
ESP32 micro-ROS bridge -> /motor_output_odom
hexapod_hardware_cpp/motor_state_aggregator_node -> /hexapod/motor_state
hexapod_hardware_cpp/body_state_estimator_node -> /hexapod/kinematic_odom
hexapod_hardware_cpp/weighted_odom_fusion_node -> /odom + odom->base_link
slam_toolbox -> map->odom + /map
```

The tripod controller is launched with `command_output_mode:=phase`, so it interfaces through `hexapod_control_interfaces/msg/LegPhaseCommand` instead of bypassing the host hardware stack.

Launch with ORB-SLAM bridge and slam_toolbox already running:

```bash
ros2 launch hexapod_nav2_bringup hexapod_nav2.launch.py \
  start_orbslam_slamtoolbox:=false \
  start_hardware_stack:=true \
  start_tripod_controller:=true
```

Launch all container-side pieces:

```bash
ros2 launch hexapod_nav2_bringup hexapod_nav2.launch.py \
  start_orbslam_slamtoolbox:=true \
  start_hardware_stack:=true \
  start_tripod_controller:=true
```

Sanity checks:

```bash
ros2 topic hz /scan
ros2 topic hz /hexapod/orbslam_odom
ros2 topic hz /hexapod/motor_state
ros2 topic hz /odom
ros2 run tf2_ros tf2_echo odom base_link
ros2 run tf2_ros tf2_echo map odom
ros2 topic echo /motor_rpm_cmd
```

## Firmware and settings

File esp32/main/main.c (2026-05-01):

/**
 * @file main.c
 * @brief Direct motor-RPM micro-ROS bridge main entry with precharge /
 * contactor control and shared-servo enable handling.
 */

#include <stdbool.h>
#include <stdint.h>

#include "driver/uart.h"
#include "esp_log.h"
#include "esp_rom_sys.h"
#include "esp_system.h"
#include "freertos/FreeRTOS.h"
#include "freertos/task.h"
#include "nvs_flash.h"
#include "rmw_microros/rmw_microros.h"

#include "dsy_rs485_servo.h"
#include "esp32_serial_transport.h"
#include "hexapod_hw_config.h"
#include "motor_power_manager.h"
#include "motor_velocity_bridge.h"

#ifndef CONFIG_MICRO_ROS_UART_BAUD_RATE
#define CONFIG_MICRO_ROS_UART_BAUD_RATE 115200
#endif

#ifndef CONFIG_MICRO_ROS_UART_RX_BUFFER_SIZE
#define CONFIG_MICRO_ROS_UART_RX_BUFFER_SIZE 1024
#endif

#ifndef CONFIG_MICRO_ROS_UART_TX_BUFFER_SIZE
#define CONFIG_MICRO_ROS_UART_TX_BUFFER_SIZE 1024
#endif

#ifndef CONFIG_MICRO_ROS_APP_STACK
#define CONFIG_MICRO_ROS_APP_STACK 8192
#endif

#ifndef CONFIG_MICRO_ROS_APP_TASK_PRIO
#define CONFIG_MICRO_ROS_APP_TASK_PRIO 5
#endif

#ifndef CONFIG_MICRO_ROS_TASK_CORE
#define CONFIG_MICRO_ROS_TASK_CORE 0
#endif

#ifndef CONFIG_MOTOR_BRIDGE_PREPARE_RETRY_DELAY_US
#ifdef CONFIG_MOTOR_BRIDGE_PREPARE_RETRY_DELAY_MS
#define CONFIG_MOTOR_BRIDGE_PREPARE_RETRY_DELAY_US ((uint32_t)CONFIG_MOTOR_BRIDGE_PREPARE_RETRY_DELAY_MS * 1000U)
#else
#define CONFIG_MOTOR_BRIDGE_PREPARE_RETRY_DELAY_US 2000000
#endif
#endif

#ifndef CONFIG_POWER_PRECHARGE_FAILURE_RETRY_DELAY_US
#ifdef CONFIG_POWER_PRECHARGE_FAILURE_RETRY_DELAY_MS
#define CONFIG_POWER_PRECHARGE_FAILURE_RETRY_DELAY_US ((uint32_t)CONFIG_POWER_PRECHARGE_FAILURE_RETRY_DELAY_MS * 1000U)
#else
#define CONFIG_POWER_PRECHARGE_FAILURE_RETRY_DELAY_US 5000000
#endif
#endif

#ifndef CONFIG_POWER_PRECHARGE_FAILURE_RETRY_FOREVER
#define CONFIG_POWER_PRECHARGE_FAILURE_RETRY_FOREVER 1
#endif

#ifndef CONFIG_POWER_PRECHARGE_FAILURE_MAX_RETRIES
#define CONFIG_POWER_PRECHARGE_FAILURE_MAX_RETRIES 3
#endif

#ifndef CONFIG_POWER_PRECHARGE_REBOOT_AFTER_FAILED_RETRIES
#define CONFIG_POWER_PRECHARGE_REBOOT_AFTER_FAILED_RETRIES 0
#endif

#define MOTOR_BRIDGE_PREPARE_RETRY_DELAY_US         CONFIG_MOTOR_BRIDGE_PREPARE_RETRY_DELAY_US
#define MOTOR_POWER_MANAGER_TASK_STACK_BYTES        4096
#define MOTOR_POWER_MANAGER_TASK_PRIORITY           3

static TickType_t ticks_from_microseconds(uint32_t timeout_us)
{
    if (timeout_us == 0U) {
        return 0;
    }

    const uint32_t timeout_ms_ceil = (timeout_us + 999U) / 1000U;
    TickType_t timeout_ticks = pdMS_TO_TICKS(timeout_ms_ceil);
    return (timeout_ticks > 0) ? timeout_ticks : 1;
}

static void delay_microseconds(uint32_t delay_us)
{
    if (delay_us == 0U) {
        return;
    }

    if (delay_us < 1000U) {
        esp_rom_delay_us(delay_us);
    } else {
        vTaskDelay(ticks_from_microseconds(delay_us));
    }
}


static const char *main_log_tag = "main";
static esp32_serial_transport_config_t micro_ros_uart_transport_config = {
    .uart_port = HEXAPOD_MICROROS_UART_PORT,
    .tx_pin = HEXAPOD_MICROROS_UART_TX_GPIO,
    .rx_pin = HEXAPOD_MICROROS_UART_RX_GPIO,
    .baud_rate = CONFIG_MICRO_ROS_UART_BAUD_RATE,
    .rx_buffer_size = CONFIG_MICRO_ROS_UART_RX_BUFFER_SIZE,
    .tx_buffer_size = CONFIG_MICRO_ROS_UART_TX_BUFFER_SIZE,
};

static void force_startup_power_outputs_safe_off(void)
{
    (void)motor_power_manager_set_precharge_enabled(false);
    (void)motor_power_manager_set_contactor_enabled(false);
    (void)dsy_rs485_set_servo_enable_output(false);
}

static void wait_for_power_path_ready_before_motor_bus(void)
{
    uint32_t failed_attempt_count = 0U;

    while (true) {
        const esp_err_t startup_result = motor_power_manager_run_startup_sequence();
        if (startup_result == ESP_OK) {
            return;
        }

        failed_attempt_count++;
        force_startup_power_outputs_safe_off();

        const motor_power_manager_status_t power_status = get_motor_power_manager_status();
        ESP_LOGE(
            main_log_tag,
            "power-path startup failed attempt=%lu result=%s adc_ready=%d bus=%.2fV sensor=%dmV raw=%d elapsed=%luus; outputs forced off",
            (unsigned long)failed_attempt_count,
            esp_err_to_name(startup_result),
            power_status.adc_ready ? 1 : 0,
            power_status.latest_bus_voltage_v,
            power_status.latest_sensor_millivolts,
            power_status.latest_raw_adc_count,
            (unsigned long)power_status.precharge_elapsed_us);

#if CONFIG_POWER_PRECHARGE_FAILURE_RETRY_FOREVER
        ESP_LOGW(
            main_log_tag,
            "retrying power-path startup in %d us",
            (int)CONFIG_POWER_PRECHARGE_FAILURE_RETRY_DELAY_US);
        delay_microseconds(CONFIG_POWER_PRECHARGE_FAILURE_RETRY_DELAY_US);
#else
        if (failed_attempt_count < (uint32_t)CONFIG_POWER_PRECHARGE_FAILURE_MAX_RETRIES) {
            ESP_LOGW(
                main_log_tag,
                "retrying power-path startup in %d us (%lu/%d failures)",
                (int)CONFIG_POWER_PRECHARGE_FAILURE_RETRY_DELAY_US,
                (unsigned long)failed_attempt_count,
                (int)CONFIG_POWER_PRECHARGE_FAILURE_MAX_RETRIES);
            delay_microseconds(CONFIG_POWER_PRECHARGE_FAILURE_RETRY_DELAY_US);
        } else {
#if CONFIG_POWER_PRECHARGE_REBOOT_AFTER_FAILED_RETRIES
            ESP_LOGE(
                main_log_tag,
                "precharge failed %d times; rebooting because menuconfig requests reboot",
                (int)CONFIG_POWER_PRECHARGE_FAILURE_MAX_RETRIES);
            delay_microseconds(250000U);
            esp_restart();
#else
            ESP_LOGE(
                main_log_tag,
                "precharge failed %d times; entering fail-stop with precharge, contactor, and servo-enable off",
                (int)CONFIG_POWER_PRECHARGE_FAILURE_MAX_RETRIES);
            while (true) {
                force_startup_power_outputs_safe_off();
                delay_microseconds(1000000U);
            }
#endif
        }
#endif
    }
}

void app_main(void)
{
    esp_err_t nvs_result = nvs_flash_init();
    if ((nvs_result != ESP_OK) &&
        (nvs_result != ESP_ERR_NVS_NO_FREE_PAGES) &&
        (nvs_result != ESP_ERR_NVS_NEW_VERSION_FOUND)) {
        ESP_LOGE(main_log_tag, "nvs_flash_init failed: %s", esp_err_to_name(nvs_result));
        return;
    }

    if ((nvs_result == ESP_ERR_NVS_NO_FREE_PAGES) ||
        (nvs_result == ESP_ERR_NVS_NEW_VERSION_FOUND)) {
        ESP_ERROR_CHECK(nvs_flash_erase());
        ESP_ERROR_CHECK(nvs_flash_init());
    }

    dsy_rs485_restore_default_servo_enable_active_level();
    ESP_ERROR_CHECK(dsy_rs485_initialize_servo_enable_output());
    ESP_ERROR_CHECK(dsy_rs485_set_servo_enable_output(false));
    ESP_LOGI(
        main_log_tag,
        "startup forced shared servo-enable OFF gpio_level=%d active_level_cfg=%d active_level_runtime=%d gpio=%d",
        dsy_rs485_get_servo_enable_gpio_level(),
        (int)HEXAPOD_SERVO_ENABLE_ACTIVE_LEVEL,
        dsy_rs485_get_servo_enable_active_level_runtime(),
        (int)HEXAPOD_SERVO_ENABLE_GPIO);
    ESP_ERROR_CHECK(motor_power_manager_initialize());

    xTaskCreate(
        motor_power_manager_task,
        "motor_power_manager_task",
        MOTOR_POWER_MANAGER_TASK_STACK_BYTES,
        NULL,
        MOTOR_POWER_MANAGER_TASK_PRIORITY,
        NULL);

    wait_for_power_path_ready_before_motor_bus();

    while (true) {
        const esp_err_t prepare_result = motor_velocity_bridge_prepare_drives_before_ros();
        if (prepare_result == ESP_OK) {
            break;
        }

        dsy_rs485_restore_default_servo_enable_active_level();
        (void)dsy_rs485_set_servo_enable_output(false);
        dsy_rs485_debug_log_servo_enable_line("main_prepare_failed_forced_off");
        ESP_LOGW(
            main_log_tag,
            "pre-ROS motor bridge startup failed: %s; forced servo-enable GPIO %d back to servo-off state before retry in %d us",
            esp_err_to_name(prepare_result),
            (int)HEXAPOD_SERVO_ENABLE_GPIO,
            MOTOR_BRIDGE_PREPARE_RETRY_DELAY_US);
        delay_microseconds(MOTOR_BRIDGE_PREPARE_RETRY_DELAY_US);
    }

#if defined(RMW_UXRCE_TRANSPORT_CUSTOM)
    rmw_uros_set_custom_transport(
        true,
        (void *)&micro_ros_uart_transport_config,
        esp32_serial_open,
        esp32_serial_close,
        esp32_serial_write,
        esp32_serial_read);
#else
#error micro-ROS transport must be built with RMW_UXRCE_TRANSPORT=custom
#endif

    ESP_LOGI(
        main_log_tag,
        "starting direct motor-RPM bridge on UART%d baud=%d precharge=%d contactor=%d bus_adc=%d servo_en=%d ros_core=%d",
        (int)micro_ros_uart_transport_config.uart_port,
        micro_ros_uart_transport_config.baud_rate,
        (int)HEXAPOD_PRECHARGE_SSR_GPIO,
        (int)HEXAPOD_CONTACTOR_SSR_GPIO,
        (int)HEXAPOD_PRECHARGE_SENSE_ADC_GPIO,
        (int)HEXAPOD_SERVO_ENABLE_GPIO,
        CONFIG_MICRO_ROS_TASK_CORE);

    esp32_serial_silence_console_logging_if_requested(&micro_ros_uart_transport_config);

    xTaskCreatePinnedToCore(
        motor_velocity_bridge_task,
        "motor_velocity_bridge_task",
        CONFIG_MICRO_ROS_APP_STACK,
        NULL,
        CONFIG_MICRO_ROS_APP_TASK_PRIO,
        NULL,
        CONFIG_MICRO_ROS_TASK_CORE);
}

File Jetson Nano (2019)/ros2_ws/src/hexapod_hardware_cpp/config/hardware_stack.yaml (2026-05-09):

wt901_imu_node:
  ros__parameters:
    serial_device: /dev/ttyTHS1
    baud_rate: 9600
    use_cached_baud: true
    cache_file: ""
    frame_id: imu_link
    publish_euler_topic: true
    accel_lpf_alpha: 0.35
    gyro_lpf_alpha: 0.35
    angle_lpf_alpha: 0.25
    yaw_offset_rad: 0.0
    xy_axes_quarter_turns_cw: 1
    accel_bias_mps2: [0.0, 0.0, 0.0]
    gyro_bias_rps: [0.0, 0.0, 0.0]
    angle_bias_rad: [0.0, 0.0, 0.0]
    accel_axis_sign: [1.0, 1.0, 1.0]
    gyro_axis_sign: [1.0, 1.0, 1.0]
    angle_axis_sign: [1.0, 1.0, 1.0]
    orientation_covariance_diag: [0.02, 0.02, 0.04]
    angular_velocity_covariance_diag: [0.01, 0.01, 0.02]
    linear_acceleration_covariance_diag: [0.1, 0.1, 0.15]

imu_udp_export_node:
  ros__parameters:
    enabled: true
    input_topic: /imu/data_raw
    # If the ORB-SLAM3 process runs on the Jetson host and the ROS 2 container
    # uses --network host, 127.0.0.1 reaches the host process. If the container
    # is bridged, set this to the Jetson host LAN IP visible from the container.
    target_ip: 127.0.0.1
    target_port: 5015
    use_header_stamp: true
    include_frame_id: true
    include_orientation: true
    # 0.0 forwards every IMU sample. Increase to rate-limit, e.g. 0.005 for 200 Hz.
    min_publish_period_s: 0.0
    print_every_n_packets: 250

motor_state_aggregator_node:
  ros__parameters:
    input_topic: /motor_output_odom
    motor_id_map: [3, 2, 1, 4, 5, 6]
    # Canonical host leg order is [rf, rm, rb, lf, lm, lb].
    # ESP odometry wire order is [rb, rm, rf, lf, lm, lb].
    canonical_to_wire_index: [2, 1, 0, 3, 4, 5]
    # Direct /motor_rpm_cmd subscription lets the phase observer unwrap raw
    # single-turn encoder counts even when commands are published externally
    # instead of through phase_command_router_node.
    subscribe_direct_rpm_commands: true
    direct_rpm_command_topic: /motor_rpm_cmd
    wire_to_canonical_index: [2, 1, 0, 3, 4, 5]
    # Canonical order [rf, rm, rb, lf, lm, lb]. These signs convert physical
    # motor encoder/RPM direction into the linkage model's positive phase.
    physical_to_model_phase_sign: [-1.0, -1.0, -1.0, 1.0, 1.0, 1.0]
    # The ESP32 publishes raw single-turn motor encoder counts, not absolute
    # gearbox-output phase. At boot/launch, all cranks are physically indexed
    # downward, so the first raw count for each leg becomes that leg's model
    # zero reference. phase_offset_rad is therefore the model phase of the
    # downward crank pose, not a correction for raw encoder count spread.
    phase_offset_rad: [0.0, 0.0, 0.0, 0.0, 0.0, 0.0]
    anchor_raw_encoder_to_startup_phase: true
    hold_last_direct_rpm_command: true
    direct_rpm_command_timeout_s: 1.0
    actuation_state_topic: hexapod/actuation_state
    stale_timeout_s: 0.25
    phase_rate_from_phase_diff_weight: 0.75
    phase_rate_from_command_weight: 0.25
    phase_rate_lowpass_alpha: 0.4
    encoder_counts_per_motor_rev: 131072.0
    gearbox_ratio: 50.0
    raw_encoder_blend_alpha: 0.65
    raw_encoder_count_quantization: true
    # Latest ESP32 firmware reuses output_phase_rad[] for raw P18.32/P18.33
    # single-turn encoder counts. Because the ESP publishes a cached six-element
    # vector while its RS485 task updates one drive at a time, unchanged raw counts
    # during a nonzero command are treated as stale cached samples, not as proof
    # that the leg stopped.
    raw_encoder_change_threshold_counts: 0.5
    ignore_unchanged_raw_encoder_when_commanded: true
    motor_speed_accel_ms: 250.0
    motor_speed_decel_ms: 250.0
    motor_speed_accel_rpm_per_s: 0.0
    motor_speed_decel_rpm_per_s: 0.0
    phase_prediction_innovation_limit_turns: 0.75
    near_zero_command_phase_rate_rad_s: 0.05
    max_phase_rate_rad_s: 8.0
    transport_split_to_host: 0.5
    delay_lowpass_alpha: 0.25
    default_measurement_age_s: 0.02
    default_future_apply_delay_s: 0.02
    max_history_size: 128
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

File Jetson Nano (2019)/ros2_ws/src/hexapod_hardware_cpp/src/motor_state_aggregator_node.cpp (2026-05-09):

#include <dsy_motor_msgs/msg/motor_output_odometry_array.hpp>
#include <dsy_motor_msgs/msg/motor_rpm_array.hpp>
#include <hexapod_control_interfaces/msg/hexapod_motor_state.hpp>
#include <hexapod_control_interfaces/msg/leg_actuation_state.hpp>
#include <rclcpp/rclcpp.hpp>

#include <algorithm>
#include <array>
#include <cmath>
#include <cstdint>
#include <deque>
#include <string>
#include <unordered_map>
#include <vector>

namespace hexapod_hardware_cpp
{

namespace
{
double wrap_to_pi(double angle_rad)
{
  while (angle_rad > M_PI) angle_rad -= 2.0 * M_PI;
  while (angle_rad < -M_PI) angle_rad += 2.0 * M_PI;
  return angle_rad;
}

float as_float_seconds(uint64_t dt_us)
{
  return static_cast<float>(1.0e-6 * static_cast<double>(dt_us));
}

std::array<std::size_t, 6> parse_index_map(
  const std::vector<int64_t> & values,
  const std::array<std::size_t, 6> & fallback)
{
  if (values.size() != 6U) {
    return fallback;
  }
  std::array<std::size_t, 6> out{};
  std::array<bool, 6> seen{};
  for (std::size_t i = 0; i < 6U; ++i) {
    if (values[i] < 0 || values[i] > 5) {
      return fallback;
    }
    const auto idx = static_cast<std::size_t>(values[i]);
    if (seen[idx]) {
      return fallback;
    }
    out[i] = idx;
    seen[idx] = true;
  }
  return out;
}

std::array<double, 6> parse_double_array(
  const std::vector<double> & values,
  const std::array<double, 6> & fallback)
{
  if (values.size() != 6U) {
    return fallback;
  }
  std::array<double, 6> out{};
  for (std::size_t i = 0; i < 6U; ++i) {
    if (!std::isfinite(values[i])) {
      return fallback;
    }
    out[i] = values[i];
  }
  return out;
}

constexpr std::array<std::size_t, 6> kDefaultCanonicalToWireIndex{{2, 1, 0, 3, 4, 5}};
// canonical [rf, rm, rb, lf, lm, lb] <- wire [rb, rm, rf, lf, lm, lb]
constexpr std::array<std::size_t, 6> kDefaultWireToCanonicalIndex{{2, 1, 0, 3, 4, 5}};
// wire [rb, rm, rf, lf, lm, lb] -> canonical [rf, rm, rb, lf, lm, lb]
constexpr std::array<double, 6> kDefaultPhysicalToModelPhaseSign{{-1.0, -1.0, -1.0, 1.0, 1.0, 1.0}};
// canonical [rf, rm, rb, lf, lm, lb]; right-side physical encoder/RPM direction is opposite model-positive phase.
constexpr std::array<double, 6> kDefaultPhaseOffsetRad{{0.0, 0.0, 0.0, 0.0, 0.0, 0.0}};

}  // namespace

class MotorStateAggregatorNode : public rclcpp::Node
{
public:
  MotorStateAggregatorNode()
  : Node("motor_state_aggregator_node")
  {
    input_topic_ = declare_parameter<std::string>("input_topic", "/motor_output_odom");
    direct_rpm_command_topic_ = declare_parameter<std::string>("direct_rpm_command_topic", "/motor_rpm_cmd");
    subscribe_direct_rpm_commands_ = declare_parameter<bool>("subscribe_direct_rpm_commands", true);
    hold_last_direct_rpm_command_ = declare_parameter<bool>("hold_last_direct_rpm_command", true);
    direct_rpm_command_timeout_s_ = declare_parameter<double>("direct_rpm_command_timeout_s", 1.0);
    motor_id_map_ = declare_parameter<std::vector<int64_t>>(
      "motor_id_map", std::vector<int64_t>{3, 2, 1, 4, 5, 6});
    canonical_to_wire_index_ = parse_index_map(
      declare_parameter<std::vector<int64_t>>(
        "canonical_to_wire_index", std::vector<int64_t>{2, 1, 0, 3, 4, 5}),
      kDefaultCanonicalToWireIndex);
    wire_to_canonical_index_ = parse_index_map(
      declare_parameter<std::vector<int64_t>>(
        "wire_to_canonical_index", std::vector<int64_t>{2, 1, 0, 3, 4, 5}),
      kDefaultWireToCanonicalIndex);
    physical_to_model_phase_sign_ = parse_double_array(
      declare_parameter<std::vector<double>>(
        "physical_to_model_phase_sign", std::vector<double>{-1.0, -1.0, -1.0, 1.0, 1.0, 1.0}),
      kDefaultPhysicalToModelPhaseSign);
    phase_offset_rad_ = parse_double_array(
      declare_parameter<std::vector<double>>(
        "phase_offset_rad", std::vector<double>{0.0, 0.0, 0.0, 0.0, 0.0, 0.0}),
      kDefaultPhaseOffsetRad);
    anchor_raw_encoder_to_startup_phase_ = declare_parameter<bool>("anchor_raw_encoder_to_startup_phase", true);
    actuation_state_topic_ = declare_parameter<std::string>("actuation_state_topic", "hexapod/actuation_state");
    stale_timeout_s_ = declare_parameter<double>("stale_timeout_s", 0.25);
    phase_rate_from_phase_diff_weight_ = declare_parameter<double>("phase_rate_from_phase_diff_weight", 0.75);
    phase_rate_from_command_weight_ = declare_parameter<double>("phase_rate_from_command_weight", 0.25);
    phase_rate_lowpass_alpha_ = declare_parameter<double>("phase_rate_lowpass_alpha", 0.4);
    max_phase_rate_rad_s_ = declare_parameter<double>("max_phase_rate_rad_s", 8.0);
    encoder_counts_per_motor_rev_ = declare_parameter<double>("encoder_counts_per_motor_rev", 131072.0);
    gearbox_ratio_ = declare_parameter<double>("gearbox_ratio", 50.0);
    raw_encoder_blend_alpha_ = declare_parameter<double>("raw_encoder_blend_alpha", 0.65);
    raw_encoder_count_quantization_ = declare_parameter<bool>("raw_encoder_count_quantization", true);
    raw_encoder_change_threshold_counts_ = declare_parameter<double>("raw_encoder_change_threshold_counts", 0.5);
    ignore_unchanged_raw_encoder_when_commanded_ = declare_parameter<bool>("ignore_unchanged_raw_encoder_when_commanded", true);
    motor_speed_accel_ms_ = declare_parameter<double>("motor_speed_accel_ms", 250.0);
    motor_speed_decel_ms_ = declare_parameter<double>("motor_speed_decel_ms", 250.0);
    motor_speed_accel_rpm_per_s_ = declare_parameter<double>("motor_speed_accel_rpm_per_s", 0.0);
    motor_speed_decel_rpm_per_s_ = declare_parameter<double>("motor_speed_decel_rpm_per_s", 0.0);
    phase_prediction_innovation_limit_turns_ = declare_parameter<double>("phase_prediction_innovation_limit_turns", 0.75);
    near_zero_command_phase_rate_rad_s_ = declare_parameter<double>("near_zero_command_phase_rate_rad_s", 0.05);
    transport_split_to_host_ = declare_parameter<double>("transport_split_to_host", 0.5);
    delay_lowpass_alpha_ = declare_parameter<double>("delay_lowpass_alpha", 0.25);
    default_measurement_age_s_ = declare_parameter<double>("default_measurement_age_s", 0.02);
    default_future_apply_delay_s_ = declare_parameter<double>("default_future_apply_delay_s", 0.02);
    max_history_size_ = declare_parameter<int>("max_history_size", 128);

    pub_ = create_publisher<hexapod_control_interfaces::msg::HexapodMotorState>("hexapod/motor_state", 10);

    sub_ = create_subscription<dsy_motor_msgs::msg::MotorOutputOdometryArray>(
      input_topic_, rclcpp::SensorDataQoS(), std::bind(&MotorStateAggregatorNode::on_odometry, this, std::placeholders::_1));

    actuation_sub_ = create_subscription<hexapod_control_interfaces::msg::LegActuationState>(
      actuation_state_topic_, 10, std::bind(&MotorStateAggregatorNode::on_actuation_state, this, std::placeholders::_1));
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

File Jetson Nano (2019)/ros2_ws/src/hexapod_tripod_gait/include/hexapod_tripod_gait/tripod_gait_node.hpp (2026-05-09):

#ifndef HEXAPOD_TRIPOD_GAIT__TRIPOD_GAIT_NODE_HPP_
#define HEXAPOD_TRIPOD_GAIT__TRIPOD_GAIT_NODE_HPP_

#include <array>
#include <chrono>
#include <cstdint>
#include <memory>
#include <string>
#include <vector>

#include "dsy_motor_msgs/msg/motor_output_odometry_array.hpp"
#include "dsy_motor_msgs/msg/motor_rpm_array.hpp"
#include "geometry_msgs/msg/twist.hpp"
#include "geometry_msgs/msg/twist_stamped.hpp"
#include "geometry_msgs/msg/vector3.hpp"
#include "geometry_msgs/msg/vector3_stamped.hpp"
#include "hexapod_control_interfaces/msg/hexapod_motor_state.hpp"
#include "hexapod_control_interfaces/msg/leg_phase_command.hpp"
#include "rclcpp/rclcpp.hpp"
#include "sensor_msgs/msg/imu.hpp"

namespace hexapod_tripod_gait
{

class TripodGaitNode : public rclcpp::Node
{
public:
  explicit TripodGaitNode(const rclcpp::NodeOptions & options = rclcpp::NodeOptions());

private:
  using MotorOutputOdometryArray = dsy_motor_msgs::msg::MotorOutputOdometryArray;
  using MotorRpmArray = dsy_motor_msgs::msg::MotorRpmArray;
  using HexapodMotorState = hexapod_control_interfaces::msg::HexapodMotorState;
  using LegPhaseCommand = hexapod_control_interfaces::msg::LegPhaseCommand;
  using Imu = sensor_msgs::msg::Imu;
  using Twist = geometry_msgs::msg::Twist;
  using TwistStamped = geometry_msgs::msg::TwistStamped;
  using Vector3 = geometry_msgs::msg::Vector3;
  using Vector3Stamped = geometry_msgs::msg::Vector3Stamped;
  using SteadyTime = std::chrono::steady_clock::time_point;

  static constexpr std::size_t motor_count = 6U;
  static constexpr double pi = 3.141592653589793238462643383279502884;

  enum LegIndex : std::size_t
  {
    right_back = 0U,
    right_middle = 1U,
    right_front = 2U,
    left_front = 3U,
    left_middle = 4U,
    left_back = 5U,
  };

  struct PlanarCommand
  {
    double linear_x_mps = 0.0;
    double angular_z_radps = 0.0;
  };

  void declare_and_load_parameters();
  std::array<double, motor_count> get_double_array_parameter(
    const std::string & name,
    const std::array<double, motor_count> & fallback);
  std::array<double, motor_count> get_sign_array_parameter(
    const std::string & name,
    const std::array<double, motor_count> & fallback);
  std::array<std::size_t, motor_count> get_index_array_parameter(
    const std::string & name,
    const std::array<std::size_t, motor_count> & fallback);

  void twist_callback(const Twist::SharedPtr message);
  void twist_stamped_callback(const TwistStamped::SharedPtr message);
  void odometry_callback(const MotorOutputOdometryArray::SharedPtr message);
  void motor_state_callback(const HexapodMotorState::SharedPtr message);
  void imu_callback(const Imu::SharedPtr message);
  void euler_callback(const Vector3Stamped::SharedPtr message);
  void euler_vector_callback(const Vector3::SharedPtr message);
  void publish_timer_callback();

  PlanarCommand get_feedback_adjusted_command(SteadyTime now) const;
  std::array<double, motor_count> compute_phase_correction_rpm(bool phase_lock_allowed) const;
  std::array<double, motor_count> compute_unlimited_motor_rpm(
    bool command_active,
    const PlanarCommand & command) const;
  std::array<int16_t, motor_count> limit_and_quantize_motor_rpm(
    const std::array<double, motor_count> & target_motor_rpm,
    bool immediate_stop);
  void publish_rpm_command(const std::array<int16_t, motor_count> & motor_rpm);
  void publish_phase_command(const std::array<int16_t, motor_count> & motor_rpm);
  double motor_rpm_to_output_phase_velocity(double motor_rpm) const;
  bool command_output_mode_is_phase() const;

  void update_euler_measurement(double roll_rad, double pitch_rad, double yaw_rad);
  void update_euler_measurement_from_vector(const Vector3 & vector_message);
  void update_linear_velocity_estimate(const Imu & message, SteadyTime now);
  double get_selected_forward_acceleration(const Imu & message) const;
  bool get_latest_roll_pitch(SteadyTime now, double & roll_rad, double & pitch_rad) const;
  bool is_command_recent(SteadyTime now) const;
  bool is_odometry_recent(SteadyTime now) const;
  bool is_imu_recent(SteadyTime now) const;
  bool is_euler_recent(SteadyTime now) const;
  bool is_effectively_zero_command() const;
  double compute_tilt_scale(double roll_rad, double pitch_rad) const;
  double wrap_to_pi(double angle_rad) const;
  double clamp_double(double value, double minimum, double maximum) const;
  void quaternion_to_roll_pitch_yaw(
    double x,
    double y,
    double z,
    double w,
    double & roll_rad,
    double & pitch_rad,
    double & yaw_rad) const;

  rclcpp::Subscription<Twist>::SharedPtr twist_subscription_;
  rclcpp::Subscription<TwistStamped>::SharedPtr twist_stamped_subscription_;
  rclcpp::Subscription<MotorOutputOdometryArray>::SharedPtr odometry_subscription_;
  rclcpp::Subscription<HexapodMotorState>::SharedPtr motor_state_subscription_;
  rclcpp::Subscription<Imu>::SharedPtr imu_subscription_;
  rclcpp::Subscription<Vector3Stamped>::SharedPtr euler_subscription_;
  rclcpp::Subscription<Vector3>::SharedPtr euler_vector_subscription_;
  rclcpp::Publisher<MotorRpmArray>::SharedPtr rpm_publisher_;
  rclcpp::Publisher<LegPhaseCommand>::SharedPtr phase_command_publisher_;
  rclcpp::TimerBase::SharedPtr publish_timer_;

  std::string cmd_vel_topic_;
  std::string cmd_vel_stamped_topic_;
  std::string odometry_topic_;
  std::string motor_state_topic_;
  std::string rpm_command_topic_;
  std::string phase_command_topic_;
  std::string command_output_mode_;
  std::string imu_topic_;
  std::string euler_topic_;
  std::string euler_vector_topic_;
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

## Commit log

2026-03-08 basic control mujoco simulation
    [base_link.stl, base_link__1.stl, controllers.yaml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]
2026-03-08 esp32 working code
2026-03-09 cpg control added for body stability
    [gait_phase_controller.yaml]
